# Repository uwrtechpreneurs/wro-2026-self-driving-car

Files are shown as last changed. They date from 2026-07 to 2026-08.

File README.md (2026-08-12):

# UWR TechPreneurs  WRO Future Engineers 2026: Self Driving Cars

This repository contains the engineering documentation for **UWR TechPreneurs**' robot for the 2026 World Robot Olympiad Future Engineers competition. The robot was designed and built by a two-student team under the guidance of their coach.

---

## Table of Contents

- [The Team](#the-team)
- [The Challenge](#the-challenge)
- [Photos of the Robot](#photos-of-the-robot)
- [Performance Videos](#performance-videos)
- [Strategy](#strategy)
- [Mobility Management](#mobility-management)
  * [Drivetrain](#drivetrain)
  * [Steering System](#steering-system)
  * [Chassis](#chassis)
- [Power and Sense Management](#power-and-sense-management)
  * [Battery](#battery)
  * [Compute — Raspberry Pi 5 and Teensy 4.0](#compute)
  * [Camera Module](#camera-module)
  * [LiDAR](#lidar)
  * [IMU](#imu)
  * [Bill of Materials (BOM)](#bill-of-materials-bom)
  * [Circuit Diagram](#circuit-diagram)
  * [Power Budget](#power-budget)
- [Software Architecture](#software-architecture)
  * [Sensor Fusion](#sensor-fusion)
  * [Computer Vision](#computer-vision)
  * [Control Systems](#control-systems)
- [Navigation System](#navigation-system)
  * [Open Challenge — State Machine](#open-challenge--state-machine)
  * [Obstacle Challenge — State Machine](#obstacle-challenge--state-machine)
  * [Behaviour](#behaviour-obstacle-challenge-only)
- [Pseudo Code](#pseudo-code)
- [Obstacle Management](#obstacle-management)
  * [Open Challenge Strategy](#open-challenge-strategy)
  * [Obstacle Challenge Strategy](#obstacle-challenge-strategy)
  * [Parking Strategy](#parking-strategy)
- [Build / Compile / Upload Instructions](#build--compile--upload-instructions)
- [Repository Structure](#repository-structure)
- [Cost Report](#cost-report)
- [AI Usage Disclosure](#ai-usage-disclosure)

---

# The Team

### Muhammed Fadhil PP

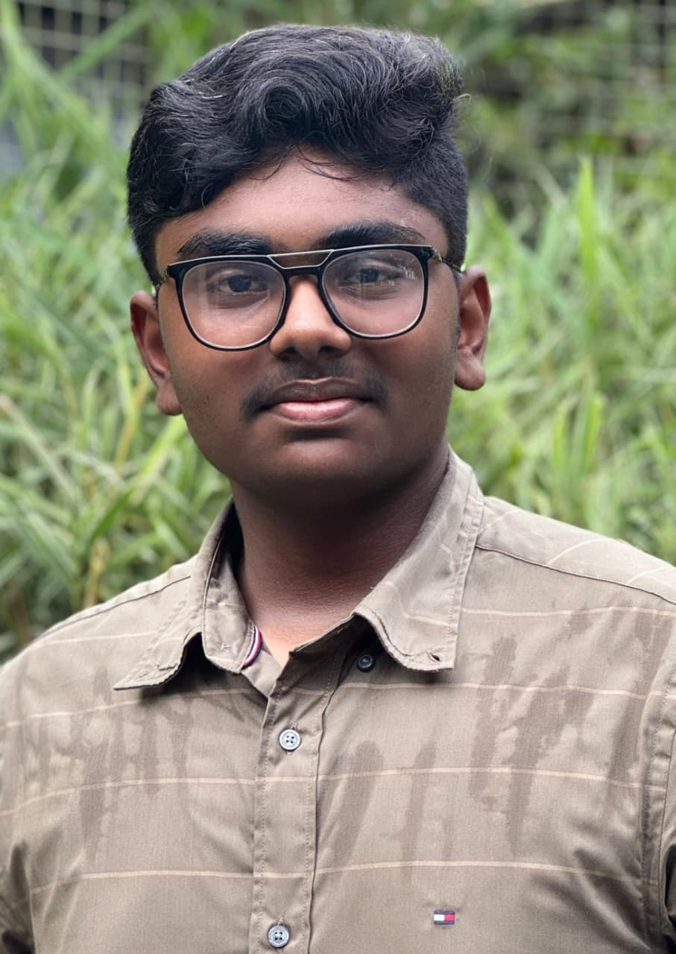
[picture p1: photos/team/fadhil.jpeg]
Fadhil


**Age:** 18

I’m Fadhil, and this is my first time in Future Engineers. We also won gold badge at nationals in Future Innovators. My expertise is hardware and mechanical design. I build the structures and mechanisms that make the robot work.

### Hani Zaman P

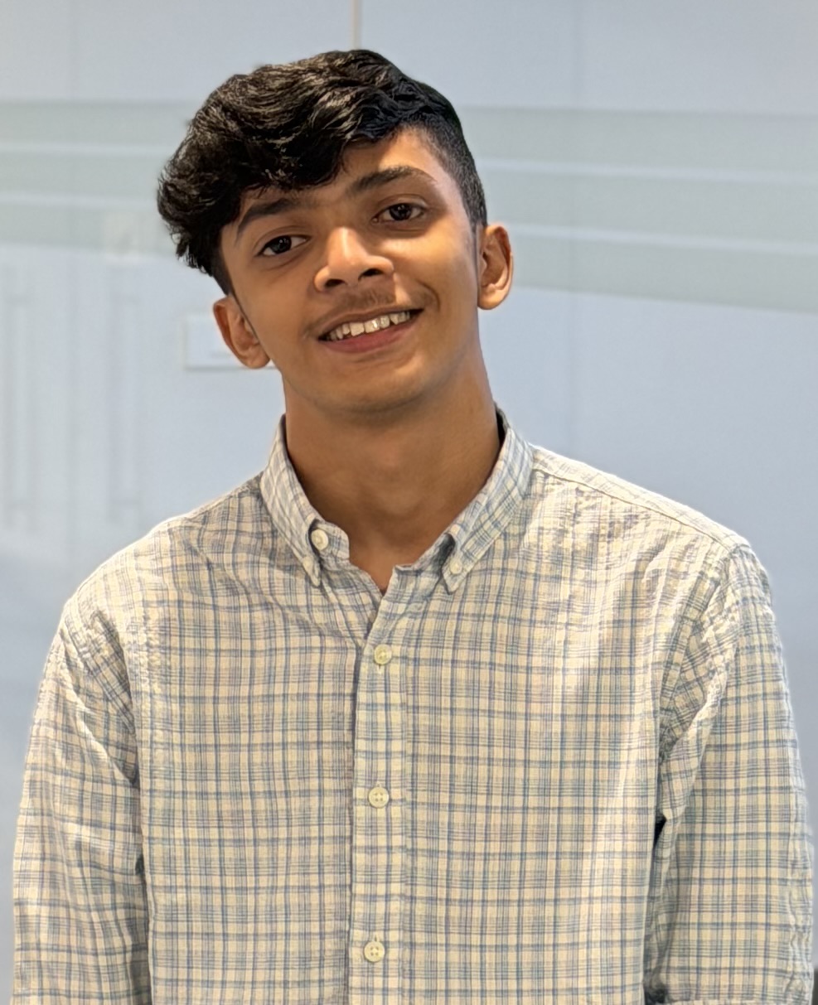
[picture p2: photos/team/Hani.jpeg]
Hani


**Age:** 18

I’m Hani, and this is my first season in Future Engineers. We won gold badge at nationals in Future Innovators with a fourth-place finish. My expertise is programming and system architecture. I focus on the logic that connects sensors, vision, and hardware into one working system.

### Jithu Joseph

**Role:** Coach

Hi, I’m Jithu. I’m the coach for this team. I mentor the team through strategy, problem-solving, and competition preparation. I bring experience in robotics and guide the team through challenges.

### Team Photo

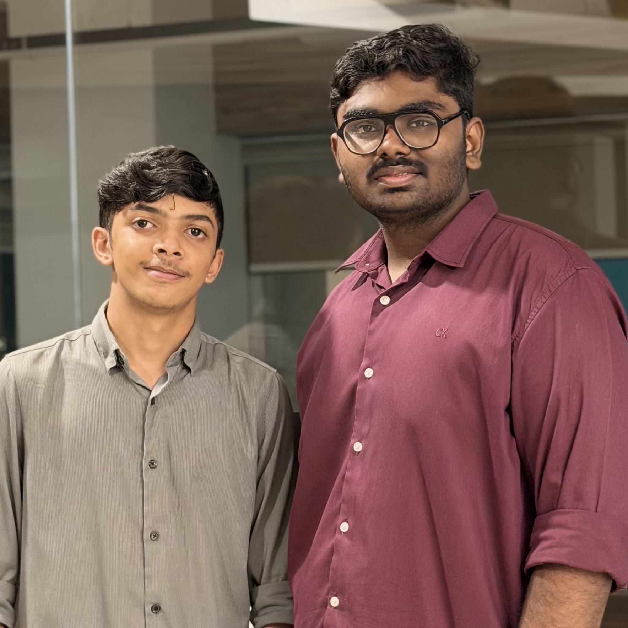
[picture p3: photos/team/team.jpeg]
Team Photo


---

# The Challenge

The **[WRO 2026 Future Engineers Self-Driving Cars](https://wro-association.org/)** challenge invites teams to design, build, and program a robotic vehicle capable of driving autonomously on a track that changes dynamically with each round. The competition includes two main rounds: the **Open Challenge**, where the robot must complete laps while staying within the track boundaries, and the **Obstacle Challenge**, where it must additionally avoid randomly placed red/green traffic pillars and complete a precise parallel parking maneuver.

This challenge emphasizes:

- **Mobility Management** - building a vehicle with precise, reliable steering and speed control.
- **Sense Management** - using sensors effectively to understand the car's position and surroundings.
- **Obstacle Handling** - detecting and correctly responding to traffic-sign pillars.
- **Parking Precision** - executing a parallel-parking maneuver within strict spatial limits.
- **Documentation** - clearly explaining engineering decisions so the robot can be understood and reproduced.

---

# Photos of the Robot

| Front | Back |
|---|---|
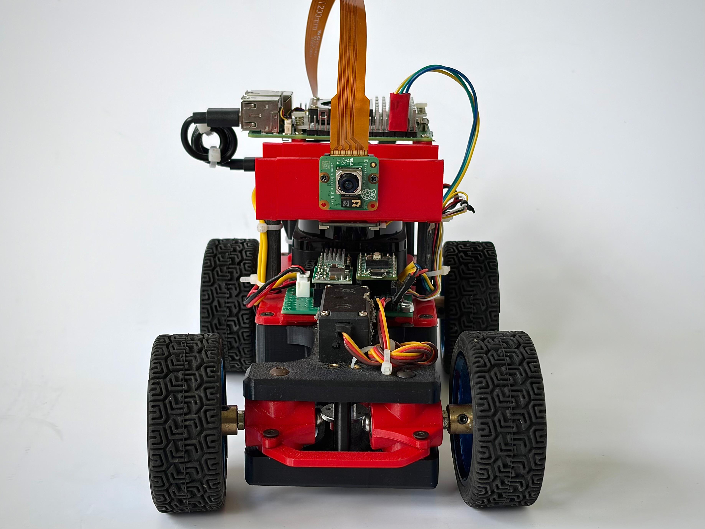
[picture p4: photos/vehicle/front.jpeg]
Front
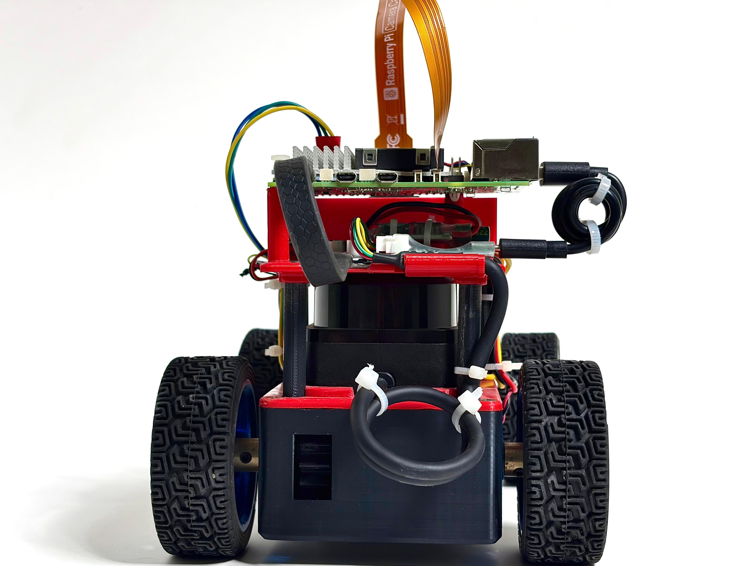
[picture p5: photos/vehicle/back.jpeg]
Back
|  |  |
| Left | Right |
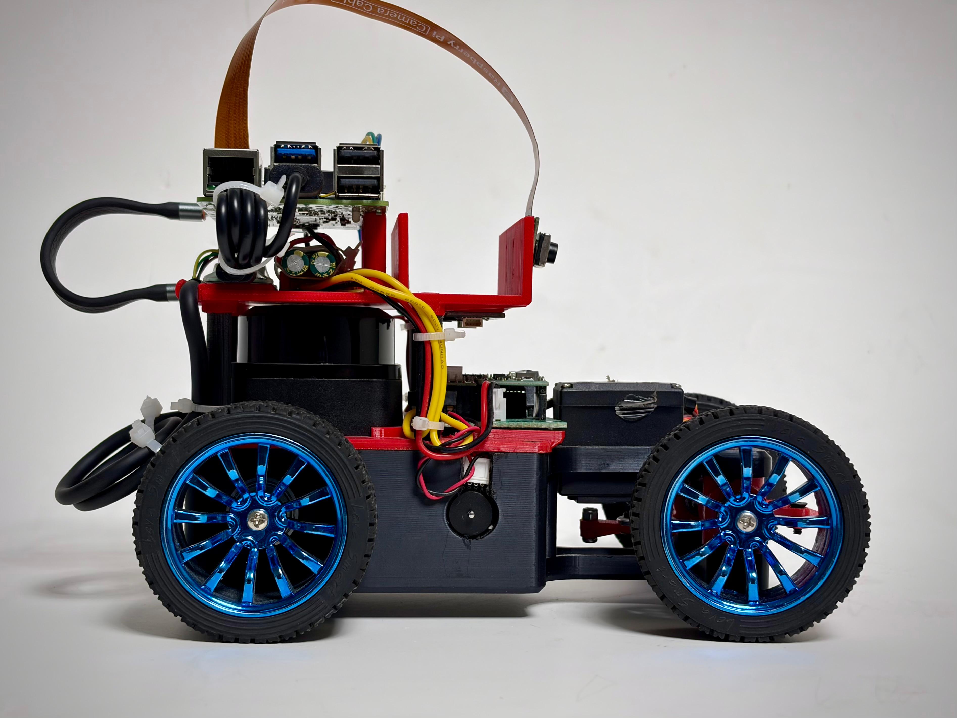
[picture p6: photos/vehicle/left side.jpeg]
Left
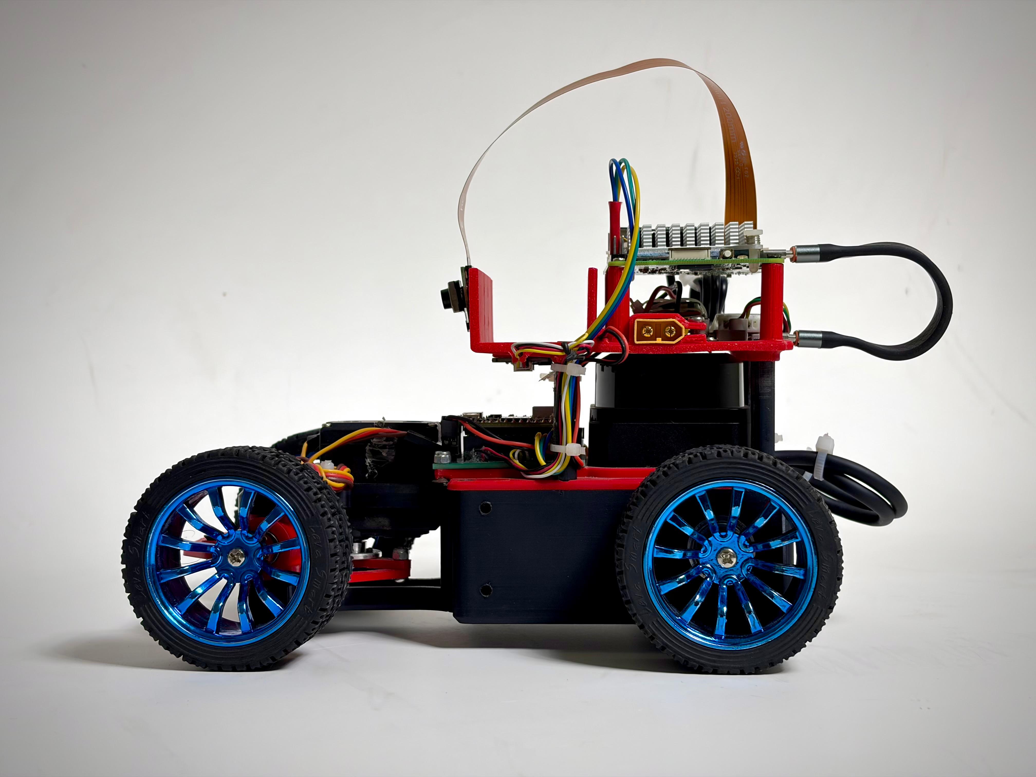
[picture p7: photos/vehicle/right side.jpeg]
Right
|  |  |
| Top | |
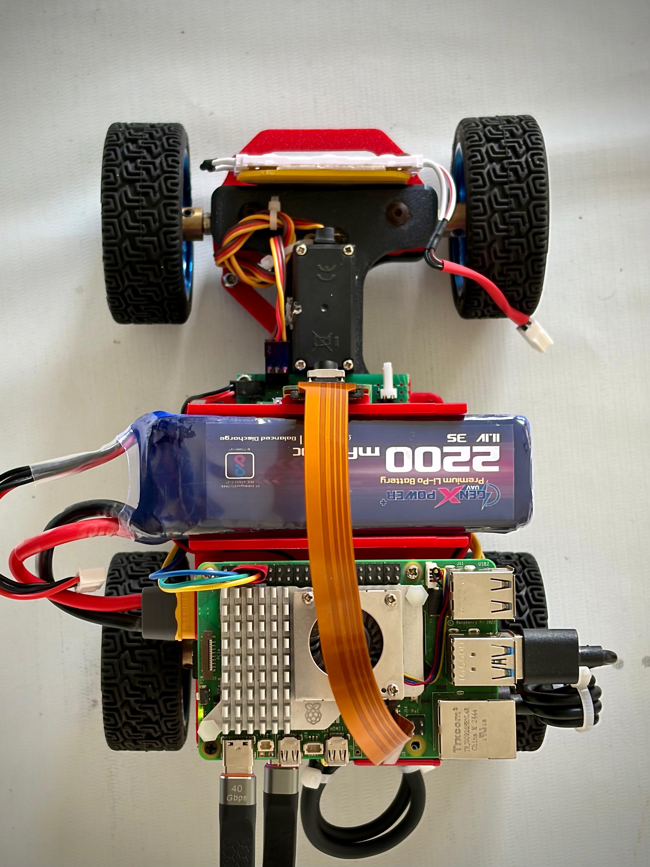
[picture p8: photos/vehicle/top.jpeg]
Top
|  | |

---

# Performance Videos

- 🎥 **Open Challenge:** https://youtu.be/rztB6XzHc4U
- 🎥 **Obstacle Challenge:** https://youtu.be/TNqtxHg5q2g

---

# Strategy

Our overall strategy prioritizes **reliability over raw speed** the robot is tuned to consistently complete a run rather than push maximum velocity at the risk of losing wall-lock or misreading a pillar.

### Open Challenge Strategy

The Open Challenge uses a two sensor fusion approach: **LiDAR** provides distance and geometry of the inner/outer boundary walls, while the **BNO055 IMU** provides continuous, high rate heading. LiDAR derived wall headings (extracted via PCA) periodically re anchor the IMU so heading stays accurate over a full run without drifting, while the IMU keeps the control loop fast between LiDAR corrections.

### Obstacle Challenge Strategy

The Obstacle Challenge strategy layers a **camera based pillar detector** on top of the same wall following core used in the Open Challenge:

1. The camera identifies red/green pillars and magenta parking markers via lab color detection.
2. A tracker (`pillar_tracker.py`) stabilizes noisy per frame detections into one reliable pillar reading.
3. Depending on the pillar's color and whether the robot is on a straight or approaching a corner, the navigator shifts its wall following lane offset left or right to pass the pillar on the correct side.
4. Once both parking markers are visible, a dedicated state sequence executes the parallel parking maneuver.

Camera based pillar avoidance only ever **nudges** the LiDAR/IMU wall following baseline   it never replaces it   which keeps the robot on track even if a pillar is briefly misdetected.

---

# Mobility Management

## Drivetrain

The robot is **rear wheel drive**, powered by a single **Waveshare L shaped permanent magnet DC gear motor** with a built in encoder. Power reaches the rear axle through a **1:1 ratio two gear system** (one gear on the motor shaft, one on the wheel axle)  this offsets the motor from the axle centerline for packaging reasons rather than changing torque/speed, since the ratio is 1:1.

Both rear wheels are rigidly fixed to the same axle/gear   there is **no differential**. This was a deliberate simplification to keep the drivetrain mechanically simple and reliable; the resulting tire scrub during turns was found to be negligible at competition speeds.

The motor is driven by a **Pololu DRV8876** H bridge motor driver, controlled by the Teensy 4.0 based on target RPM commands sent from the Pi. The motor's built in encoder is read directly by the Teensy for closed loop RPM control and tick based odometry.

## Steering System

The front axle uses **true Ackermann steering geometry**, actuated by a single **MG996R** hobby servo through the steering linkage. Ackermann geometry was chosen specifically over simpler parallel/tie rod only steering so that the inner and outer front wheels each point along their correct turning circle tangent  this reduces tire scrub during turns and, in our testing, made the car's actual turning behavior track much more closely with our LiDAR based heading and wall position calculations.

## Chassis

The chassis was **custom designed in Fusion 360** and **3D printed** in house. All CAD files are available in `/models`.

**3D-printed parts** (`/models/3d-printed`):

| Part | Render | STL |
|---|---|---|
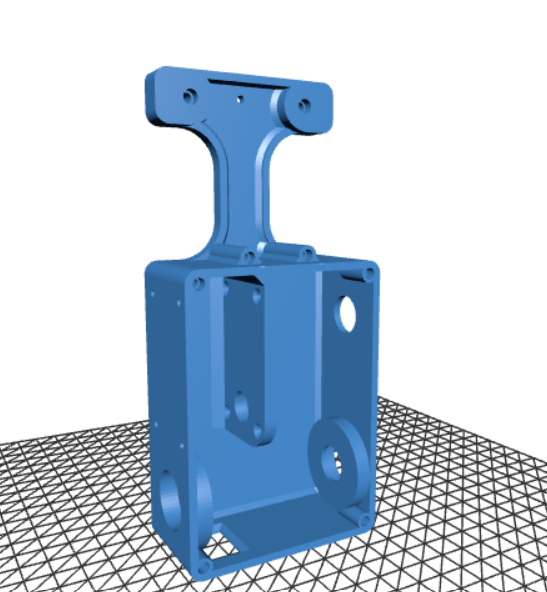
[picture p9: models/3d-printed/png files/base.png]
Base
| Base |  | [Base.stl](models/3d-printed/Base.stl) |
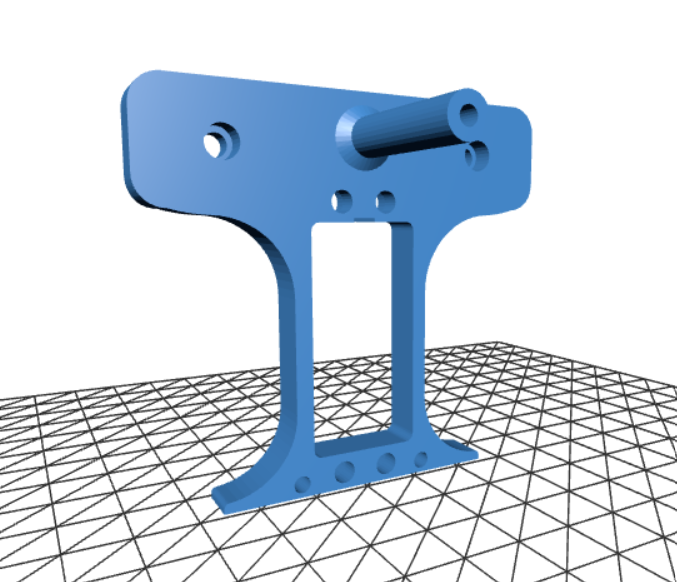
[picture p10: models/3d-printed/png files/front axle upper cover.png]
Front axle upper cover
| Front axle upper cover |  | [Front axle upper cover.stl](<models/3d-printed/Front axle upper cover.stl>) |
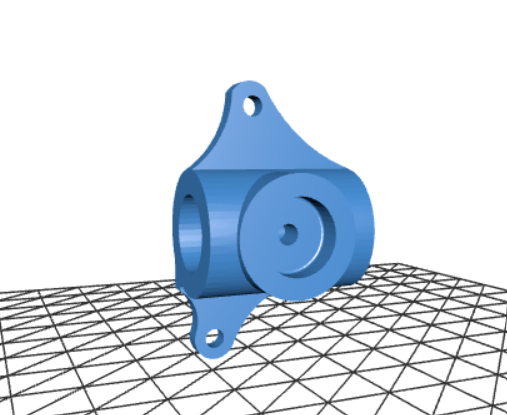
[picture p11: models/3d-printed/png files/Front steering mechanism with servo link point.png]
Front steering mechanism with servo link point
| Front steering mechanism (with servo link point) |  | [Front steering mechanism with servo link point.stl](<models/3d-printed/Front steering mechanism with servo link point.stl>) |
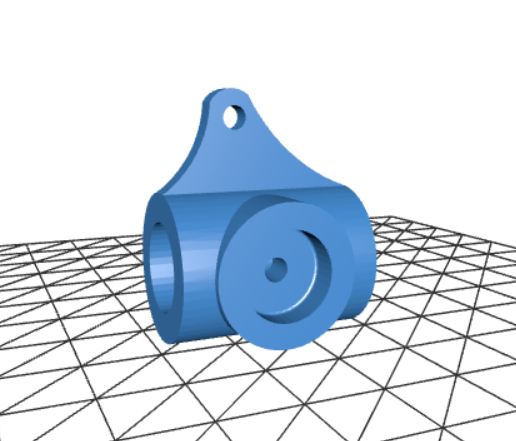
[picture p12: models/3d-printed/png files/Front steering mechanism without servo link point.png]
Front steering mechanism without servo link point
| Front steering mechanism (without servo link point) |  | [Front steering mechanism without servo link point.stl](<models/3d-printed/Front steering mechanism without servo link point.stl>) |
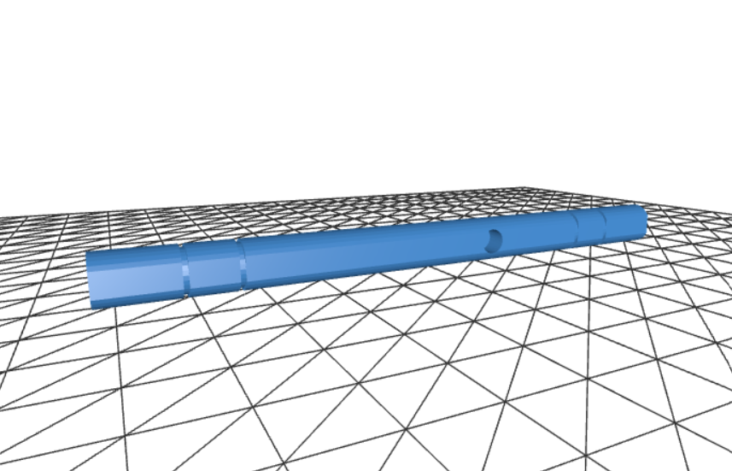
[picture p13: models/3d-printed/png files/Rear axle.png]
Rear axle
| Rear axle |  | [Rear axle.stl](<models/3d-printed/Rear axle.stl>) |
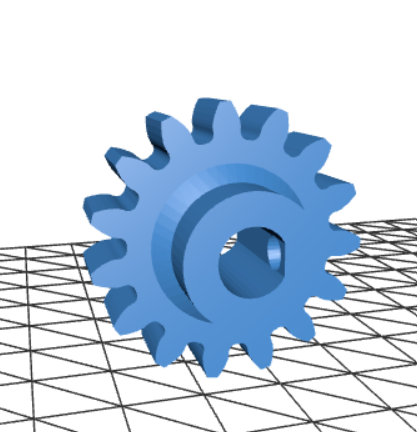
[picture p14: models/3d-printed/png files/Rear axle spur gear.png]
Rear axle spur gear
| Rear axle spur gear |  | [Rear axle spur gear.stl](<models/3d-printed/Rear axle spur gear.stl>) |
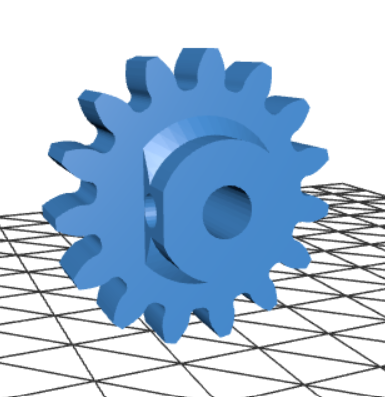
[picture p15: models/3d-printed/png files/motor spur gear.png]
Motor spur gear
| Motor spur gear |  | [motor spur gear.stl](<models/3d-printed/motor spur gear.stl>) |
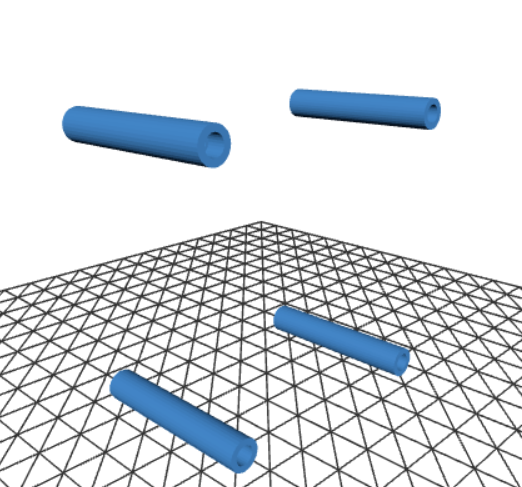
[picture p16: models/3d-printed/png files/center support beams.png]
Center support beams
| Center support beams |  | [center support beams.stl](<models/3d-printed/center support beams.stl>) |
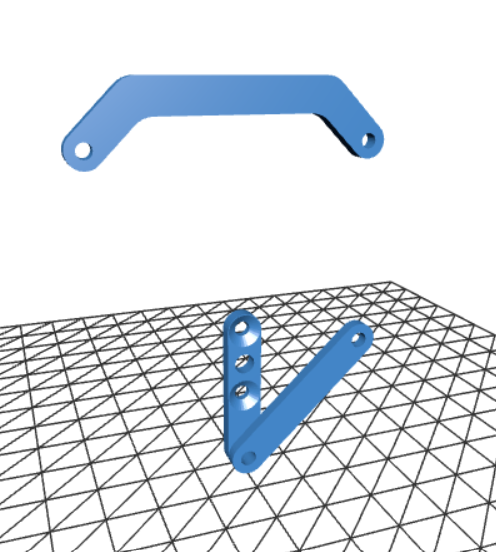
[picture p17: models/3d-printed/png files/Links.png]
Links
| Links |  | [links.stl](models/3d-printed/links.stl) |
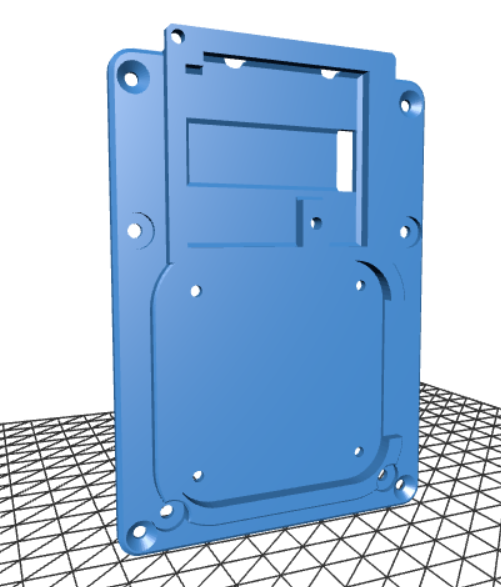
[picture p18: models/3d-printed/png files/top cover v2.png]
Top cover v2
| Top cover v2 |  | [top cover v2.stl](<models/3d-printed/top cover v2.stl>) |
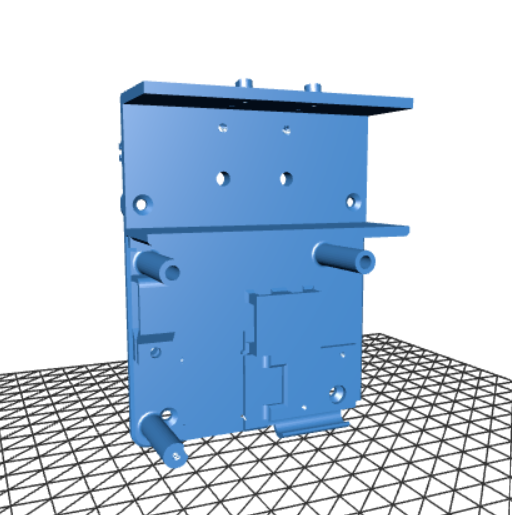
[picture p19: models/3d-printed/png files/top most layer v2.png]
Top-most layer v2
| Top-most layer v2 |  | [top most layer v2.stl](<models/3d-printed/top most layer v2.stl>) |

**Full assembly** (`/models/Assembly`):

| Render | STEP File |
|---|---|
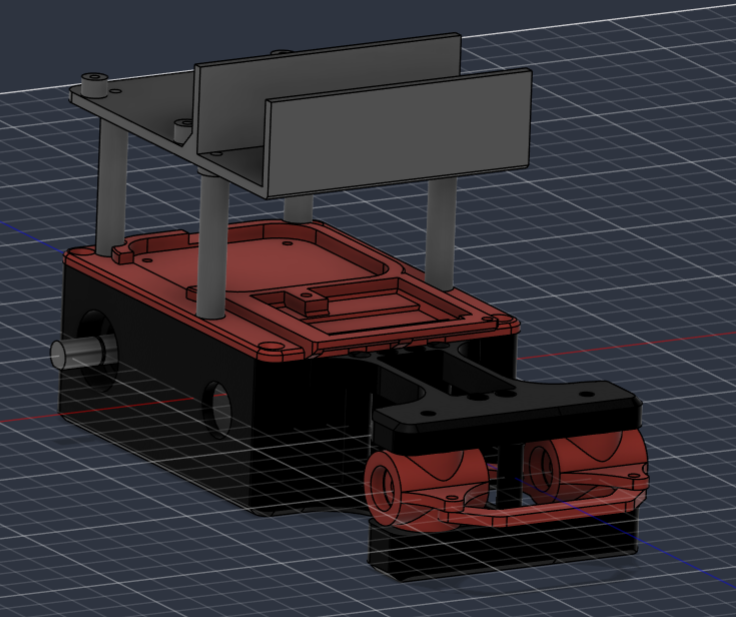
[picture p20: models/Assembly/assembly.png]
Full assembly
|  | [assembly.step](models/Assembly/assembly.step) |

---

# Power and Sense Management

## Battery

The robot is powered by a **GenX 11.1V 3S 2200mAh LiPo battery**. No separate BMS is used  charge/discharge protection is handled by the balance charger during charging, and the team monitors cell voltage manually during operation.

**Power distribution:**

| Rail | Powers | Notes |
|---|---|---|
| 65W USB PD module | Raspberry Pi 5 (and, via the Pi, the Camera Module and LiDAR) | Steps down from the main LiPo; chosen because the Pi 5 is sensitive to under voltage and benefits from PD's sustained current delivery |
| UBEC | MG996R steering servo | Isolates servo current spikes (especially under load while steering) from the rest of the system |
| Buck converter (MP1584) | Teensy 4.0 (and, via the Teensy, the BNO055 IMU and motor encoder) | Isolates the Teensy's logic supply from motor driver electrical noise |
| Motor driver (DRV8876) | Drive motor | Powered directly from the LiPo |

Splitting power into dedicated rails per subsystem was a deliberate choice to prevent brownouts on the compute boards when the servo or drive motor draws a current spike.

## Compute

- **Raspberry Pi 5**: the high level "brain." Runs LiDAR processing, camera/computer vision processing, and all navigation decision making in Python.
- **Teensy 4.0**: the real time controller. Executes low level motor/servo commands, reads the BNO055 IMU and motor encoder at high frequency, and streams telemetry back to the Pi.

The two communicate over UART with a simple custom protocol:
- Pi → Teensy: `S<rpm>,<steer>\n`
- Teensy → Pi: `T<rpm>,<ticks>,<heading>,<imu_raw>,<sys_cal>,<gyro_cal>,<accel_cal>,<mag_cal>\n`

## Camera Module

A **Raspberry Pi Camera Module 3 Wide** is used exclusively for color identification detecting red/green obstacle pillars and magenta parking lot markers via lab color thresholding. It does not participate in wall following; that is handled entirely by the LiDAR.

Distance to a detected pillar is estimated using a pinhole camera model, calibrated against the pillar's known 100mm real world height:

```
distance_mm = (pillar_real_height_mm × focal_length_px) / pixel_height
```

## LiDAR

A **SLAMTEC RPLiDAR C1M1** (spinning 360° LiDAR) is the primary spatial sense: it reads distances to the inner/outer boundary walls and any obstacle pillars around the robot. It's read via the official Slamtec SDK's `ultra_simple` binary, parsed by a background thread, rather than a Python LiDAR wrapper library, for more reliable long run stability on the Pi.

## IMU

A **BNO055 9 DOF absolute orientation sensor** is read by the Teensy 4.0 and streamed to the Pi as part of the telemetry packet, providing continuous heading at high rate. Because pure IMU heading drifts over time, it's periodically re anchored using a LiDAR derived heading (extracted via PCA over detected wall points).

## Bill of Materials (BOM)

| Component | Unit Price (₹) |
|---|---|
| Raspberry Pi 5 | 19,849.99 |
| SLAMTEC RPLiDAR C1M1 | 7,055.00 |
| Raspberry Pi Camera Module 3 Wide | 4,026.00 |
| Teensy 4.0 Development Board | 2,471.00 |
| Official Raspberry Pi 32GB Micro SD Card (A2 Class) | 1,299.00 |
| BNO055 9 DOF Absolute Orientation Sensor | 1,360.45 |
| GenX 11.1V 3S 2200mAh LiPo Battery | 1,465.00 |
| Waveshare L shaped Permanent Magnet DC Gear Motor | 1,059.00 |
| DRV8876 Motor Driver | 734.00 |
| PD65W Fast Charging Adapter Module | 175.00 |
| Ubec | 349.00 |
| MG996R Servo | 343.00 |
| Mini MP1584 Buck Module | 40.00 |
| 65mm Robot Smart Car Rim Wheel (×4) | 159.00 |
| **Total** | **≈ ₹40,385.44** |

## Circuit Diagram

 [Circuit Diagram.fzz](<schemes/Circuit Diagram/Circuit Diagram.fzz>).

## Power Budget

The power/current budget is a rough, estimated sketch (not bench measured) used at design time to size each regulator and confirm that splitting the system into separate rails would give enough headroom under worst case load:

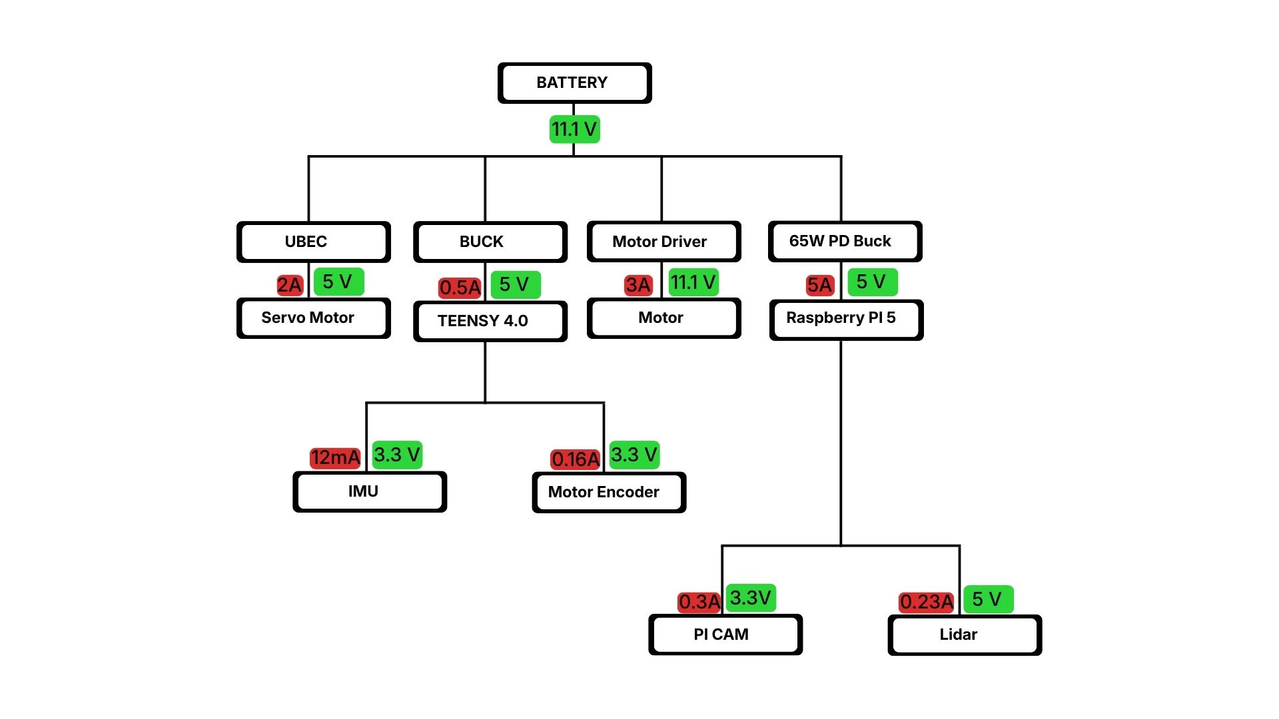
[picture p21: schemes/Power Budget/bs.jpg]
Power Budget


| Rail | Component | Voltage | Current | Power |
|---|---|---|---|---|
| 65W USB-PD module | Raspberry Pi 5 | 5V | 5.00A | 25.00W |
| ↳ (via Pi 5) | Pi Camera Module 3 Wide | 3.3V | 0.30A | 0.99W |
| ↳ (via Pi 5) | SLAMTEC RPLiDAR C1M1 | 5V | 0.23A | 1.15W |
| UBEC | MG996R Servo | 5V | 2.00A | 10.00W |
| Buck converter (MP1584) | Teensy 4.0 | 5V | 0.50A | 2.50W |
| ↳ (via Teensy) | BNO055 IMU | 3.3V | 0.012A | 0.04W |
| ↳ (via Teensy) | Motor encoder | 3.3V | 0.16A | 0.53W |
| Motor driver (DRV8876) | Drive motor | 11.1V | 3.00A | 33.30W |
| **Estimated total (worst case, all loads simultaneous)** | | | | **≈ 70.8W** |

**Power budget:**

- **Battery:** 11.1V with a continuous discharge capability of 88A (40C × 2200mAh) ≈ 977W continuously.
- **Load:** 70.8W (worst case). The battery is more than capable of handling this load.

*Run time estimation:* Sized against the **GenX 11.1V 3S 2200mAh LiPo** (≈ 24.4Wh), this worst-case draw implies roughly 20 minutes of continuous runtime if every load were maxed out simultaneously in practice the servo and motor rarely hit peak current at the same time, so real runtime per charge is considerably longer.

The rail separation wasn't driven by this power budget the battery has plenty of headroom either way. It came from testing: current spikes from sudden servo movements were noising up the logic circuits, so we isolated the servo onto its own UBEC, separate from the Teensy/microcontroller's buck converter. The Pi 5 got its own 65W PD-capable rail because it draws far more power than everything else and we initially thought it needed proper USB-PD negotiation we later found a config-file workaround for the Pi's proprietary PD protocol, but by then the PD module was already in place.

---

# Software Architecture

The codebase is organized so each module maps to one hardware responsibility, and is implemented in Python on the Pi 5 with the Teensy 4.0 handling real time control.

| Module | Responsibility |
|---|---|
| `lidar_reader.py` | Background thread wrapping the Slamtec SDK binary; exposes the latest full 360° scan as filtered angle/distance arrays |
| `wall_extractor.py` | Converts raw LiDAR scans into world frame wall segments using MAD outlier filtering + PCA, with a confidence score per wall |
| `camera_detector.py` | Background thread running Picamera2 + OpenCV lab detection for pillars and parking markers, with distance estimation |
| `pillar_tracker.py` | Temporal smoothing/stabilization of camera pillar detections |
| `teensy_bridge.py` | UART protocol handler between Pi and Teensy, running the receive loop on a background thread |
| `navigation.py` | Open Challenge state machine and wall following control logic |
| `navigator_obstacle.py` | Obstacle Challenge state machine  extends wall following with pillar based offsetting and parking |
| `logger.py` | Per cycle CSV telemetry logging (heading, wall distances, steering, RPM, calibration status, etc.) |
| `main.py` / `main_obstacle.py` | Entry points  initialize LiDAR, camera, Teensy connection, and logger, then run the respective navigator's main loop |

## Sensor Fusion

Every navigation cycle:

```
RPLiDAR ──► lidar_reader ──► wall_extractor ──► ┐
                                                  ├─► navigator ──► teensy_bridge ──► Teensy ──► motor + servo
Pi Camera ─► camera_detector ─► pillar_tracker ─┘                       ▲
                                                                          │
                                       BNO055 + encoder ─────────────────┘
                                         (via Teensy telemetry)
```

`wall_extractor.py` converts LiDAR points into world frame (corridor fixed) sectors, applies a median absolute deviation (MAD) filter to reject outliers, then fits each wall with PCA to extract its heading  with a confidence score based on point count and linearity. The navigator fuses this LiDAR derived heading with the continuous IMU heading: the IMU drives the fast control loop, while LiDAR periodically re anchors it so heading stays accurate over a full run.

## Computer Vision

`camera_detector.py` performs LAB based color segmentation to identify red/green pillars and magenta parking markers, with distance estimated from a pinhole camera model. `pillar_tracker.py` then smooths that detection over a short history, rejects impossible frame to frame jumps, and tolerates a few missed frames before dropping a pillar  giving the navigator one stable, low noise pillar reading instead of a flickery raw detection.

## Control Systems

`navigator_obstacle.py` selects a driving **behavior** (`NORMAL`, `STRAIGHT_RED`, `STRAIGHT_GREEN`, `CORNER_RED`, `CORNER_GREEN`) each cycle based on the currently tracked pillar's color and whether the robot is on a straight or approaching a corner. Each behavior shifts the wall following target offset left or right so the robot passes the pillar on the correct side without losing lane centering against the walls. Speed and steering commands are sent to the Teensy each cycle over UART.

---

# Navigation System

## Open Challenge State Machine

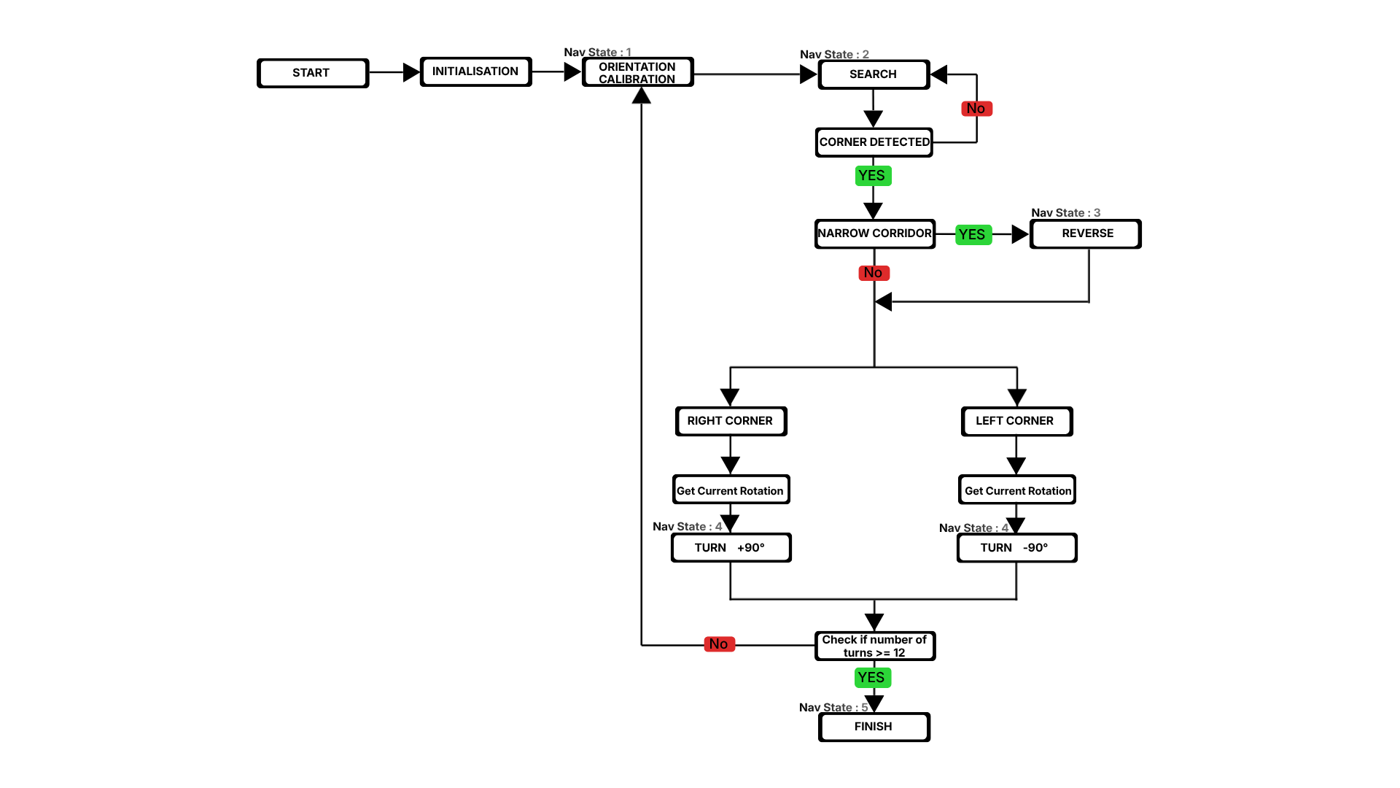
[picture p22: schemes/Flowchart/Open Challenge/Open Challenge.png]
Open Challenge Flowchart


| State | Meaning |
|---|---|
| `INITIALIZE` | Zeros the IMU, resets heading, transitions to `CALIBRATE`. |
| `CALIBRATE` | Waits for the IMU zero to settle, then extracts a LiDAR based heading (PCA over corridor walls). If confidence ≥ 0.9, anchors `heading_offset` and moves to `SEARCH`; otherwise creeps forward and retries (times out after 3s). |
| `SEARCH` | Main wall following state. Extracts wall geometry every cycle, computes a combined distance + heading steering correction, and watches for a corner opening (a wall reading with enough "far points" past a ratio threshold) to trigger a turn. |
| `REVERSE_FOR_TURN` | Entered when a corner is detected but the corridor is "narrow" (front wall closer than 690mm)  reverses until the front wall clears `TURN_START_DISTANCE`, then proceeds to `TURN`. |
| `TURN` | Executes a proportional control 90° rotation to the target heading. On completion, zeros the IMU, increments the completed corner count, and returns to `CALIBRATE`. |
| `FINISH` | Reached once all 12 corners are completed and the robot has driven past `FINISH_DISTANCE` (1850mm) on the final straight; the robot stops. |

**Heading fusion:** `rotation = imu_heading − heading_offset`, where `heading_offset` is set during `CALIBRATE` from a LiDAR PCA heading (`heading_offset = lidar_heading − imu_heading`). This lets the IMU drive the fast control loop between calibrations while LiDAR keeps it accurate over a full run.

## Obstacle Challenge State Machine

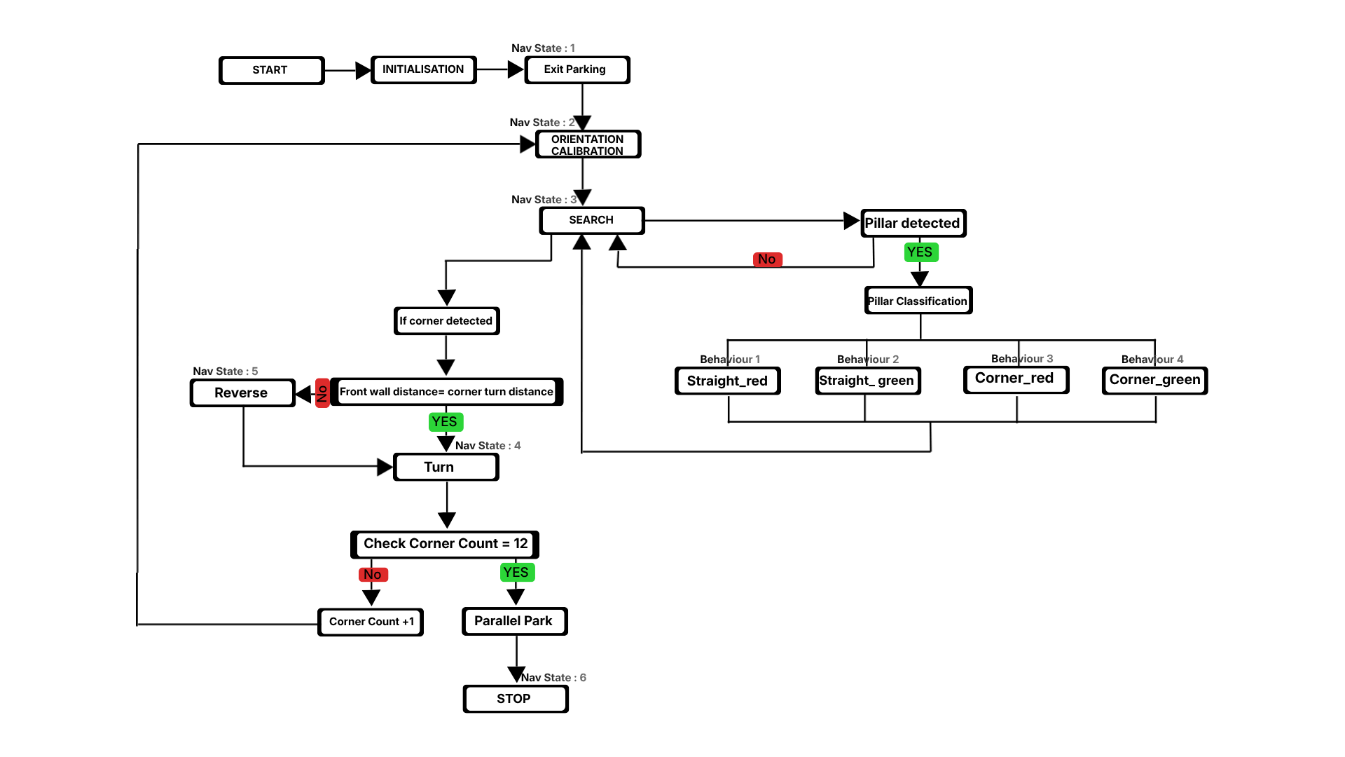
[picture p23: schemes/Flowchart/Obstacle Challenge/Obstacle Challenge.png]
Obstacle Challenge Flowchart


| State | Meaning |
|---|---|
| `INITIALIZE` | Stops the robot, zeros the IMU, resets all counters/behaviour, then moves to `EXIT_PARKING`. |
| `EXIT_PARKING` | Drives the robot out of the starting box using basic wall following until the front wall exceeds `PARKING_SEARCH_DISTANCE` (1500mm), then proceeds to `CALIBRATE`. |
| `CALIBRATE` | Same LiDAR PCA heading anchor as the Open Challenge. Uses both walls on the very first calibration, then only the outer wall after each turn. On success, resets behaviour/turn controller/wall geometry and the pillar tracker, then moves to `SEARCH`. |
| `SEARCH` | Main state: updates wall geometry, updates the pillar tracker, updates the current `Behaviour` (see below), runs the wall following controller with any active lane offset, and checks whether a turn should trigger. |
| `REVERSE_FOR_CORNER` | Entered when the front wall turn trigger distance is reached. Because a corner pillar's color can raise the trigger distance (e.g. `CORNER_RED_TURN_DISTANCE`) after the robot has already passed the default threshold, this state reverses (with heading only correction) until the front wall climbs back to the target, then begins the turn. Has a 2s safety timeout. |
| `TURN` | Same proportional 90° rotation logic as the Open Challenge. Does **not** reset behaviour that only happens in `CALIBRATE`. |
| `REVERSE_FOR_PILLAR` | Entered when a tracked straight pillar gets closer than `STRAIGHT_PILLAR_MIN_DISTANCE` (400mm). Reverses (heading corrected, no lateral offset) until the pillar is far enough away (or lost, or the 2s timeout hits), then resumes `SEARCH`. |
| `PARK` | Reached once all 12 corners are complete and the robot passes `FINISH_DISTANCE`. **Currently a placeholder**  it stops the robot. The magenta marker parking maneuver is planned but not yet implemented (see [Parking Strategy](#parking strategy)). |

## Behaviour (Obstacle Challenge only)

Each `SEARCH` cycle, `update_behaviour()` classifies the currently tracked pillar (if any) into one of five behaviours, which shift the wall following lane offset and/or the turntrigger distance:

| Behaviour | Trigger | Effect |
|---|---|---|
| `NORMAL` | No pillar tracked, or pillar already passed | No offset; default turntrigger distance. |
| `STRAIGHT_RED` | Pillar classified as "on a straight" (see below) and red | Lane offset = `STRAIGHT_RED_OFFSET` (−350mm). |
| `STRAIGHT_GREEN` | Straight pillar, green | Lane offset = `STRAIGHT_GREEN_OFFSET` (+350mm). |
| `CORNER_RED` | Pillar classified as "at a corner" and red | Turn trigger distance = `CORNER_RED_TURN_DISTANCE` (700mm). |
| `CORNER_GREEN` | Corner pillar, green | Turn trigger distance = `CORNER_GREEN_TURN_DISTANCE` (1150mm). |

A pillar is classified as "straight" vs "corner" by comparing the front wall LiDAR distance to the pillar's camera estimated distance: if `wall_front − pillar_distance > STRAIGHT_THRESHOLD` (800mm), it's a straight section pillar; otherwise it's treated as a corner pillar. Once classified, the behaviour **locks** — it won't be re derived even if the camera briefly loses or misreads the pillar — and is only cleared either when the turn actually triggers (`CORNER_*`) or when the robot has traveled far enough past a passed straight pillar (`STRAIGHT_*`).

---

# Pseudo Code

## Wall Following Controller (both challenges)

```
FUNCTION compute_distance_error():
    IF wall_left AND wall_right visible:
        distance_error = (wall_right - wall_left) / 2 - desired_offset
    ELIF only wall_left visible:
        distance_error = SINGLE_WALL_DISTANCE - wall_left + desired_offset
    ELIF only wall_right visible:
        distance_error = wall_right - SINGLE_WALL_DISTANCE - desired_offset
    ELSE:
        distance_error = 0

FUNCTION compute_steering():
    steering = KP_DISTANCE * distance_error - KP_HEADING * rotation
    steering = clamp(steering, -MAX_STEERING, MAX_STEERING)
    send_drive_command(SEARCH_RPM, steering)
```

`desired_offset` is 0 in the Open Challenge; in the Obstacle Challenge it's set by the current `Behaviour` (±350mm for straight pillar avoidance).

## Turn Trigger + Turn Execution

```
FUNCTION check_turn_trigger():
    IF turn direction not yet locked:
        look for an "opening" (enough far range LiDAR points, above a ratio
        threshold) on the left or right -> lock that as turn_direction
        RETURN

    IF wall_front > turn_start_distance:
        RETURN   # keep driving

    # trigger distance reached
    reverse_target_distance = turn_start_distance
    state = REVERSE_FOR_CORNER   # (REVERSE_FOR_TURN in Open Challenge)

FUNCTION state_turn():
    target = ±90° from heading at turn start
    error  = normalize(target - rotation)

    IF |error| <= tolerance:
        stop_robot(); zero_imu()
        completed_corners += 1
        state = CALIBRATE
        RETURN

    steering = clamp(TURN_KP * error, min_steering, max_steering)
    rpm = TURN_RPM * 0.9 IF |error| < 20 ELSE TURN_RPM
    send_drive_command(rpm, steering)
```

## Heading Calibration (LiDAR → IMU anchor)

```
FUNCTION state_calibrate():
    IF IMU not settled after zero: RETURN

    outer_wall = None IF first calibration ELSE (opposite of last turn direction)
    result = extractor.calibrate_corridor_heading(scan, outer_wall)

    IF result.heading is not None AND result.confidence >= 0.9:
        heading_offset = result.heading - imu_heading
        reset behaviour / turn controller / wall geometry / pillar tracker
        state = SEARCH
    ELSE:
        drive forward slowly and retry (give up after 3s, keep last offset)
```

## Pillar Behaviour Classification (Obstacle Challenge)

```
FUNCTION update_behaviour():
    IF behaviour is CORNER_*:
        RETURN   # locked until the turn actually triggers

    IF behaviour is STRAIGHT_*:
        IF ticks_travelled > STRAIGHT_PASS_DISTANCE_TICKS AND pillar is None:
            reset_behaviour()   # unlock
        RETURN

    # behaviour is NORMAL  free to classify a new pillar
    IF no pillar tracked OR wall_front unknown: RETURN

    delta = wall_front - pillar.distance
    IF delta > STRAIGHT_THRESHOLD:
        behaviour = STRAIGHT_RED or STRAIGHT_GREEN (by pillar colour)
        desired_offset = ±350mm
    ELSE:
        behaviour = CORNER_RED or CORNER_GREEN (by pillar colour)
        turn_start_distance = CORNER_RED_TURN_DISTANCE or CORNER_GREEN_TURN_DISTANCE
```

---

# Obstacle Management

## Open Challenge Strategy

The robot follows the corridor formed by the inner and outer boundary walls, using LiDAR-derived wall geometry fused with IMU heading (see [Sensor Fusion](#sensor-fusion)) to stay centered, and executes each required turn once the front wall distance drops below threshold. Full state definitions and flowchart: see [Navigation System](#navigation-system).

## Obstacle Challenge Strategy

1. **Detection** — the camera identifies red or green pillars by lab color and estimates distance via the pinhole model.
2. **Tracking** — `PillarTracker` stabilizes that detection across frames before the navigator trusts it.
3. **Behavior selection** — the navigator picks a behavior (`NORMAL` / `STRAIGHT_RED` / `STRAIGHT_GREEN` / `CORNER_RED` / `CORNER_GREEN`) that shifts the wall following offset so the robot passes the pillar on the correct side: red pillars are kept on the robot's right (passed on the left), green pillars the opposite.

## Parking Strategy

At the start of a run, the robot executes an **`EXIT_PARKING`** state  following the corridor out of the starting box until the front wall distance exceeds `PARKING_SEARCH_DISTANCE` (1500mm), then proceeding to `CALIBRATE`.

At the *end* of a run, once `TOTAL_CORNERS` (12) have been completed and the robot reaches the finish line, it transitions to **`PARK`**. This is currently a placeholder final state that simply stops the robot — the magenta marker based precision parking maneuver (using `CameraDetector`'s `parking` output, which already detects left/right magenta markers) is planned but not yet wired into the navigator.

---

# Build / Compile / Upload Instructions

**Hardware setup:**
1. Flash Raspberry Pi OS to the Pi 5 and enable the camera and UART interfaces via `raspi-config`.
2. Wire the RPLiDAR C1M1 to a USB port (`/dev/ttyUSB0`), and connect the Teensy 4.0 to the Pi's UART pins (`/dev/ttyAMA0`, 460800 baud).
3. Flash the Teensy 4.0 firmware (motor/servo control + BNO055 + encoder reading + UART telemetry protocol) using the Arduino IDE or Teensyduino.

**Software setup on the Pi:**
1. Install the Slamtec RPLiDAR SDK and build the `ultra_simple` binary (path referenced in `lidar_reader.py`).
2. Manually install the required Python packages: `numpy`, `opencv-python`, `picamera2`, `pyserial`.
3. Clone this repository onto the Pi.

**Running the robot:**
- Open Challenge: `python3 src/main.py`
- Obstacle Challenge: `python3 src/main_obstacle.py`

Each run automatically creates a timestamped CSV log under `logs/` for post run analysis.

---

# Repository Structure

```
/src                          → all robot control code (LiDAR, camera, navigation, Teensy bridge, logger)
/models
  /3d-printed                  → STL files for all 3D printed chassis/drivetrain parts (11 parts)
  /Assembly                    → full CAD assembly (assembly.step)
/schemes
  /Circuit Diagram              → wiring diagram (Circuit Diagram.fzz)
  /Flowchart/Open Challenge      → Open Challenge state machine flowchart (Open Challenge.png)
  /Power Budget                  → power/current budget breakdown (bs.jpg)
/photos
  /vehicle                      → front, back, left, right, + extra angle vehicle photos
  /team                         → team photo (pending)
/video                         → Open Challenge and Obstacle Challenge run videos (pending)
```

---

# Cost Report

| Category | Total (₹) |
|---|---|
| Electronic components & sensors | ≈ 40,385.44 |
| 3D-printing materials, fasteners, wiring | *(not yet itemized)* |
| **Project total (components only)** | **≈ ₹40,385.44** |

See the full [Bill of Materials](#bill-of-materials-bom) above for the itemized breakdown.

---

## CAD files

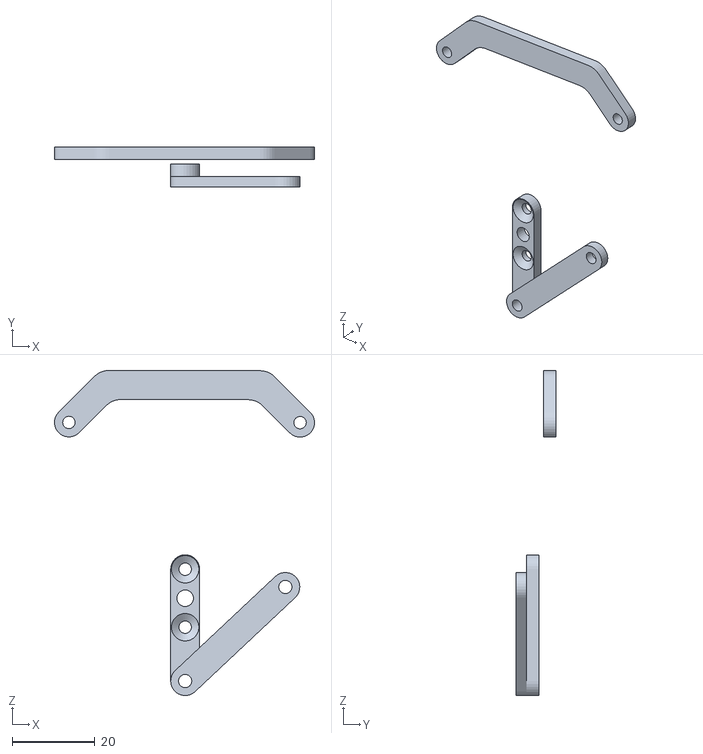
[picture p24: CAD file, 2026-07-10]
models/3d-printed/links.stl
62.8 x 9.57 x 78.5

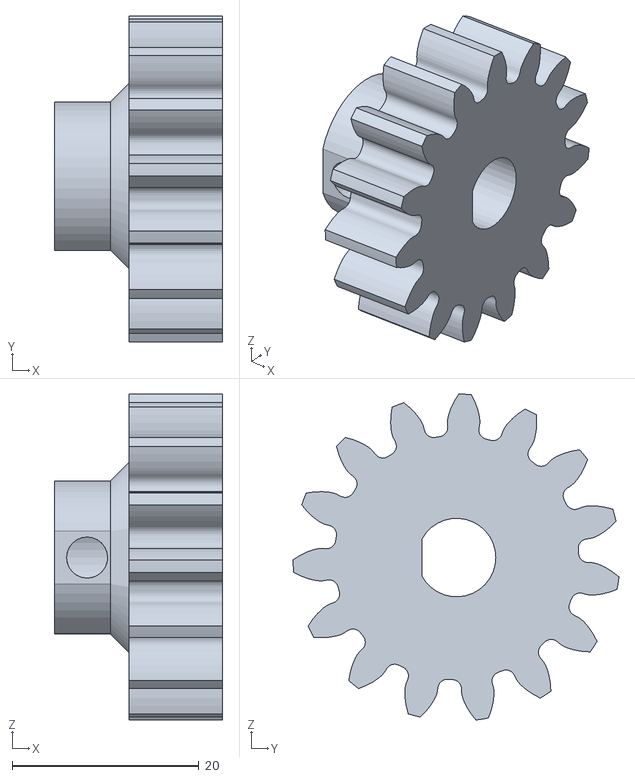
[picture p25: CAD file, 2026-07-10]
models/3d-printed/Rear axle spur gear.stl
18.0 x 34.9 x 34.9

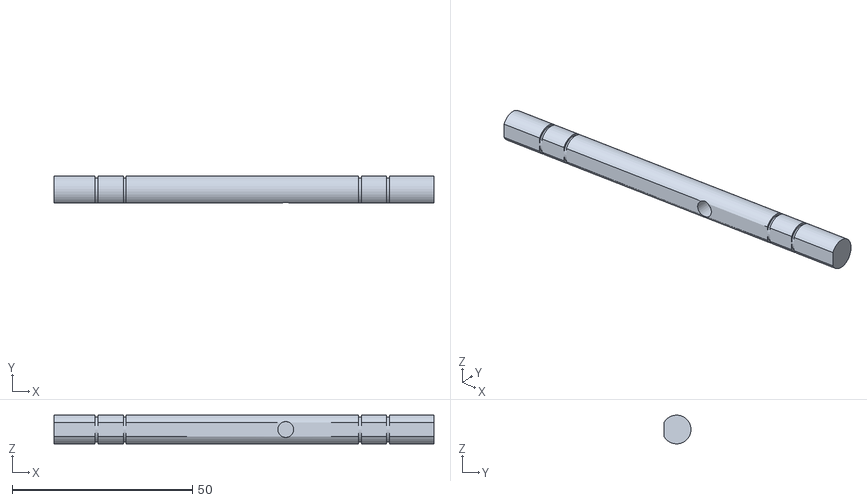
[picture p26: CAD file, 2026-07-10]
models/3d-printed/Rear axle.stl
105.5 x 7.48 x 7.97

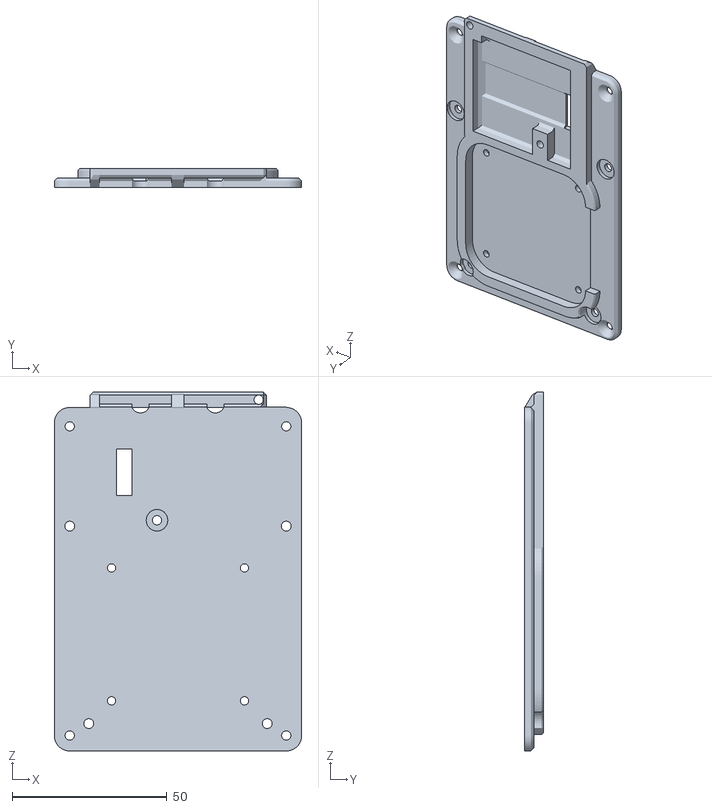
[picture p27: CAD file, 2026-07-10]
models/3d-printed/top cover v2.stl
80.1 x 6.00 x 116.2

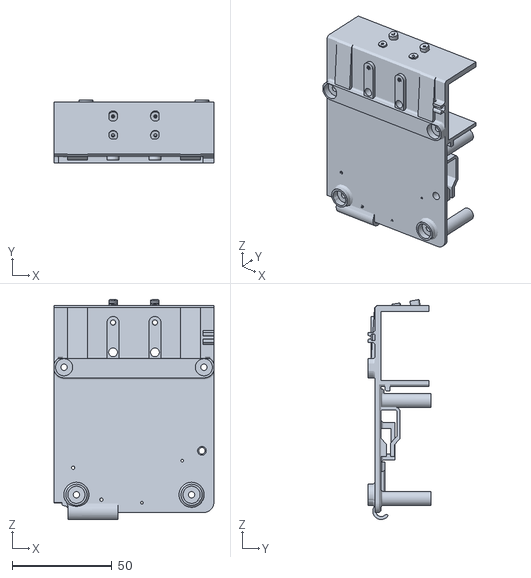
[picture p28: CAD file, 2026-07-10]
models/3d-printed/top most layer v2.stl
80.1 x 31.6 x 110.2

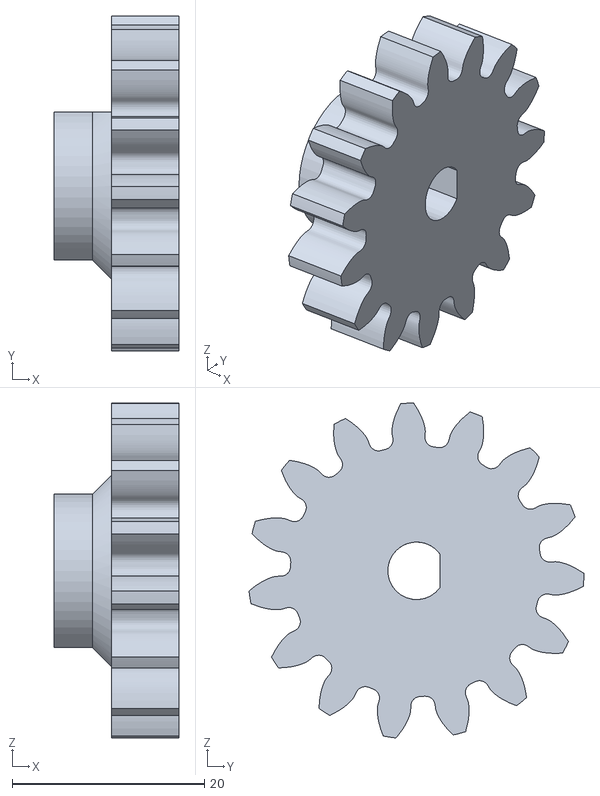
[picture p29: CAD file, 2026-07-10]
models/3d-printed/motor spur gear.stl
13.0 x 34.9 x 34.9

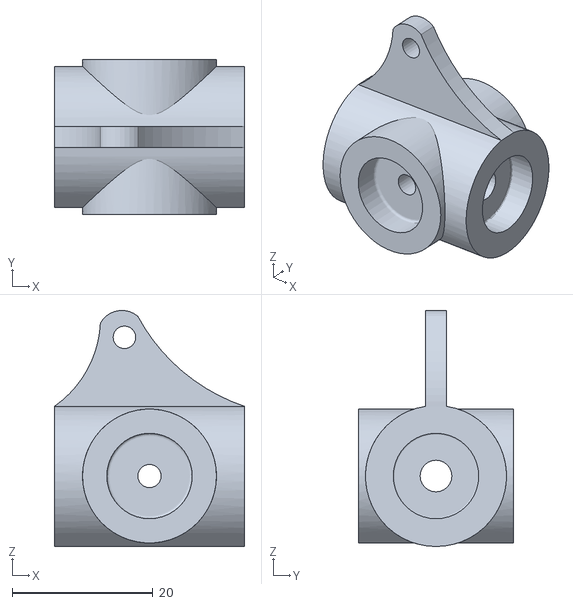
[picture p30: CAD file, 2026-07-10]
models/3d-printed/Front steering mechanism without servo link point.stl
27.0 x 22.0 x 33.5

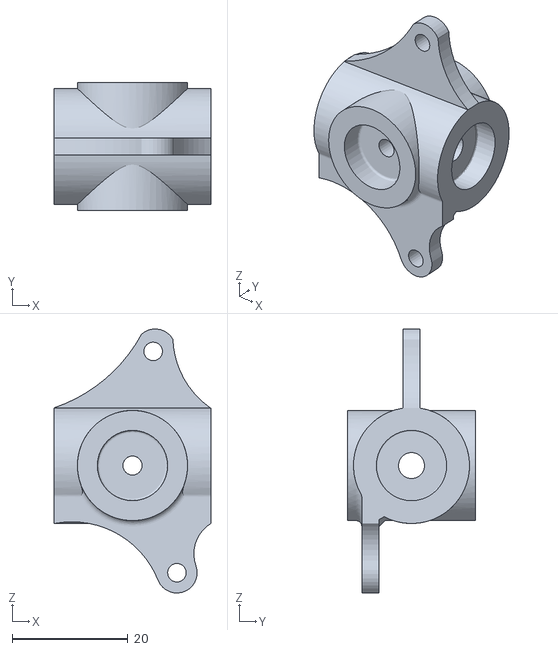
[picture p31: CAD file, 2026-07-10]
models/3d-printed/Front steering mechanism with servo link point.stl
27.0 x 22.0 x 45.5

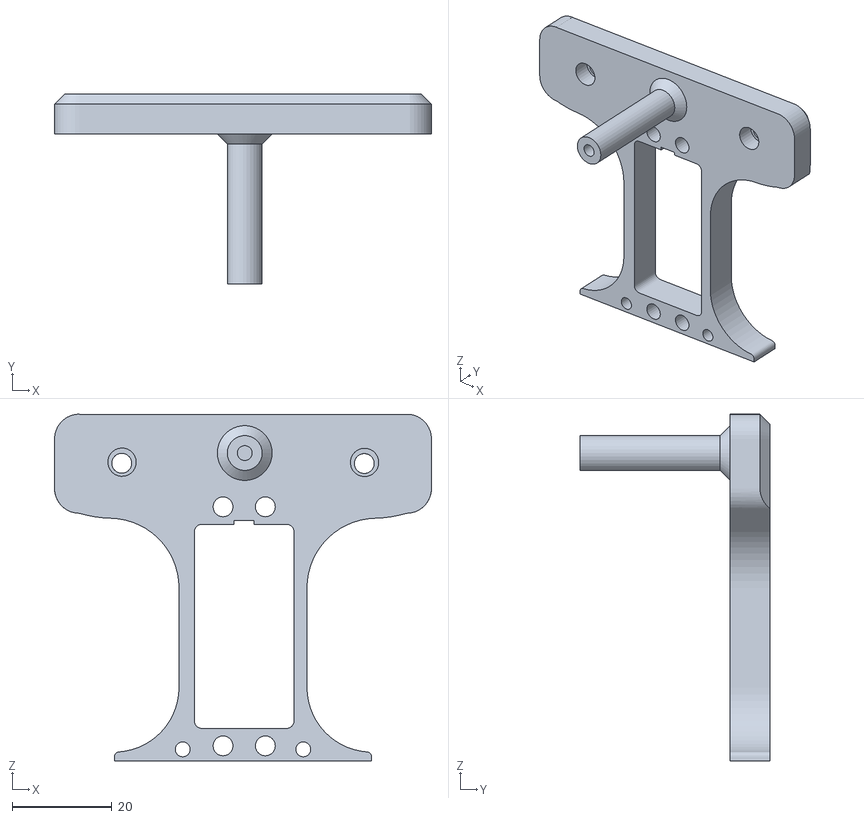
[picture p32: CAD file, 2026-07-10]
models/3d-printed/Front axle upper cover.stl
75.7 x 38.1 x 69.7

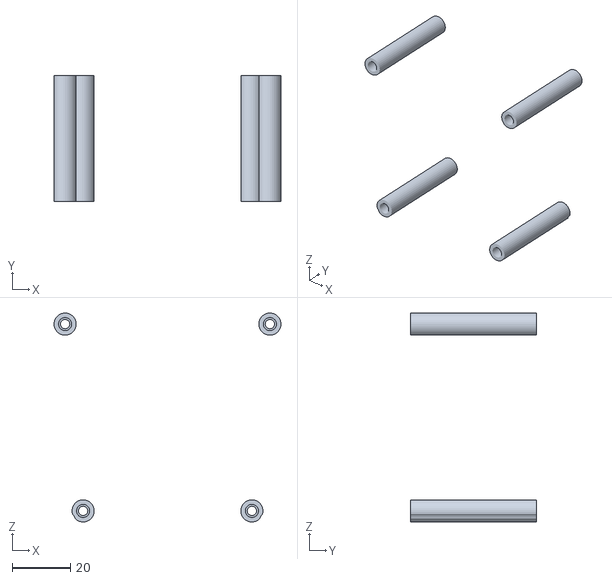
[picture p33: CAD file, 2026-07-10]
models/3d-printed/center support beams.stl
77.7 x 43.0 x 71.5

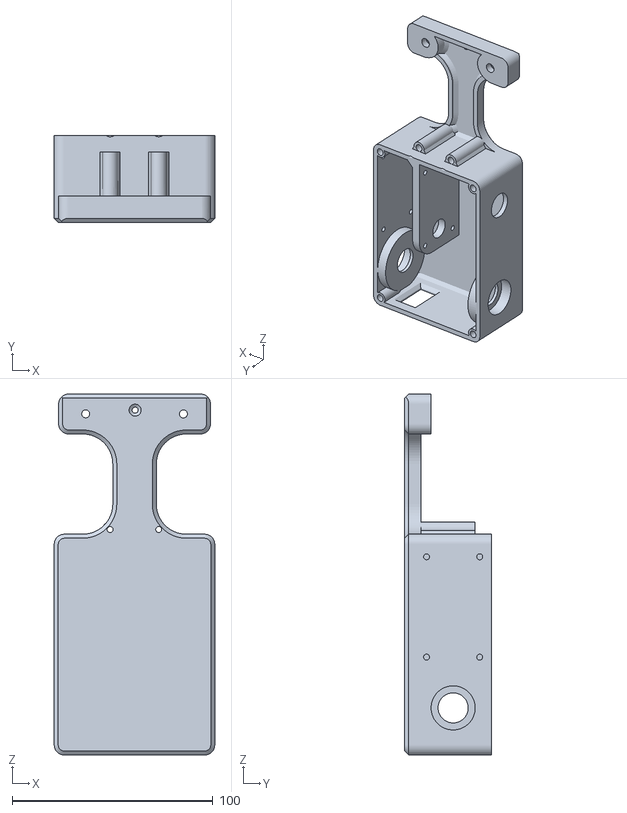
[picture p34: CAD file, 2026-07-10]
models/3d-printed/Base.stl
80.1 x 43.1 x 179.9

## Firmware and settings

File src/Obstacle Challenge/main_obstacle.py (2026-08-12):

#!/usr/bin/env python3
"""
main_obstacle.py

Main entry point for the WRO Obstacle Challenge Navigation System.


"""

import sys

from lidar_reader import LidarC1
from navigator_obstacle import Navigator
from logger import Logger


# ======================================================
# Configuration
# ======================================================

ENABLE_LOGGER = True


# ======================================================
# Logger
# ======================================================

logger = Logger() if ENABLE_LOGGER else None


# ======================================================
# Initialise LiDAR
# ======================================================

print("--------------------------------")
print("Starting LiDAR...")
print("--------------------------------")

lidar = LidarC1()
lidar.start()


# ======================================================
# Initialise Navigator
# ======================================================

print("--------------------------------")
print("Creating Navigator...")
print("--------------------------------")

navigator = Navigator(logger=logger)


# ======================================================
# Connect Teensy
# ======================================================

print("--------------------------------")
print("Connecting to Teensy...")
print("--------------------------------")

if not navigator.bridge.start():

    print("Failed to connect to Teensy")

    sys.exit(1)


# ======================================================
# Start Camera
# ======================================================

print("--------------------------------")
print("Starting Camera...")
print("--------------------------------")

navigator.camera.start()


print("--------------------------------")
print("System Ready")
print("--------------------------------")


# ======================================================
# Main Loop
# ======================================================

try:

    while True:

        angles_deg, distances_mm = lidar.get_scan()

        if len(angles_deg) == 0:
            continue

        navigator.run(
            angles_deg,
            distances_mm
        )

except KeyboardInterrupt:

    print("Keyboard interrupt")

except Exception:

    import traceback
    traceback.print_exc()

finally:

    print("\nStopping robot...")

    try:
        navigator.stop_robot()
    except Exception as e:
        print(e)

    try:
        navigator.camera.stop()
    except Exception as e:
        print(e)

    try:
        lidar.stop()
    except Exception as e:
        print(e)

    try:
        navigator.bridge.stop()
    except Exception as e:
        print(e)

    print("Shutdown complete.")

    sys.exit(0)

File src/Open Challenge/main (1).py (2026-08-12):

#!/usr/bin/env python3
"""
main.py

Main entry point for the WRO Navigation System.


"""

import serial
import sys
import time

from lidar_reader import LidarC1
from navigation import Navigator
from logger import Logger


# ======================================================
# Configuration
# ======================================================

SERIAL_PORT = "/dev/ttyAMA0"
SERIAL_BAUD = 460800

ENABLE_LOGGER = True

# ======================================================
# Initialise
# ======================================================

print("--------------------------------")
print("Starting LiDAR...")
print("--------------------------------")

lidar = LidarC1()
lidar.start()

print("--------------------------------")
print("Creating Navigator...")
print("--------------------------------")

navigator = Navigator()

if not navigator.bridge.start():

    print("Failed to connect to Teensy")

    sys.exit(1)

if ENABLE_LOGGER:

    navigator.logger = Logger()

print("--------------------------------")
print("System Ready")
print("--------------------------------")



# ======================================================
# Main Loop
# ======================================================

try:

    while True:

        angles_deg, distances_mm = lidar.get_scan()

        if len(angles_deg) == 0:
            continue

        navigator.run(
            angles_deg,
            distances_mm
        )

except KeyboardInterrupt:

    print("\nKeyboard interrupt received.")

finally:

    print("\nStopping robot...")

    try:
        navigator.stop_robot()
    except Exception as e:
        print(f"Stop robot failed: {e}")

    try:
        if navigator.logger is not None:
            navigator.logger.close()
    except Exception as e:
        print(f"Logger close failed: {e}")

    try:
        lidar.stop()
    except Exception as e:
        print(f"LiDAR stop failed: {e}")

    try:
        navigator.bridge.stop()
    except Exception as e:
        print(f"Bridge stop failed: {e}")

    print("Shutdown complete.")

    sys.exit(0)

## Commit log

2026-07-10 Create center support beams.stl
    [center support beams.stl]
2026-07-10 Create Front axle upper cover.stl
    [Front axle upper cover.stl]
2026-07-10 Create Front steering mechanism with servo link point.stl
    [Front steering mechanism with servo link point.stl]
2026-07-10 Create Front steering mechanism without servo link point.stl
    [Front steering mechanism without servo link point.stl]
2026-07-10 Create motor spur gear.stl
    [motor spur gear.stl]
2026-07-10 Create top most layer v2.stl
    [top most layer v2.stl]
2026-07-10 Create top cover v2.stl
    [top cover v2.stl]
2026-07-10 Create Rear axle.stl
    [Rear axle.stl]
2026-07-10 Create Rear axle spur gear.stl
    [Rear axle spur gear.stl]
2026-07-10 Create Circuit Diagram.fzz
    [Circuit Diagram.fzz]
2026-08-25 circuit diagram of the car
    this is a circuit diagram of our robot
2026-08-25 circuit diagram with drv8876 motor driver
